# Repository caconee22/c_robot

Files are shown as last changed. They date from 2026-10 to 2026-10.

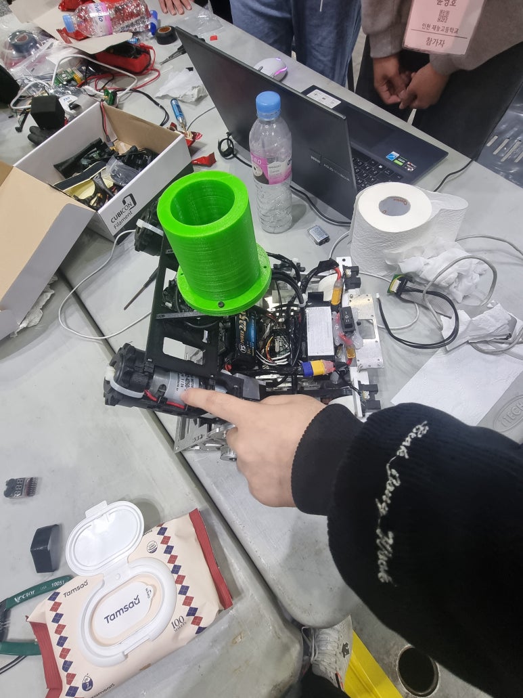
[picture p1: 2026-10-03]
img/20221027_142355.jpg

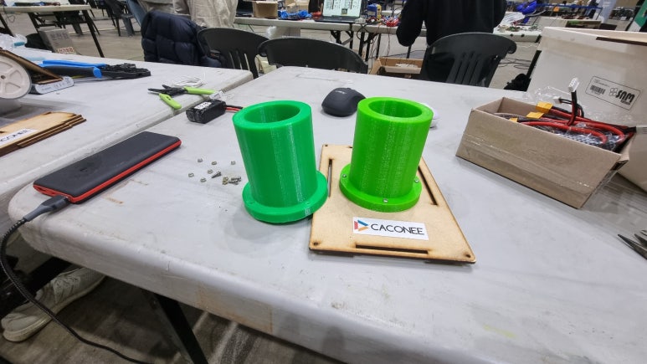
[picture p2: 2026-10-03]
img/KakaoTalk_20220726_033758780_24.jpg

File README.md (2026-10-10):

# C_ROBOT — IRC 씨름 로봇

ESP32-S3 주행 제어, 라즈베리파이 영상 처리, 회로 설계를 관리하는 저장소다.
현재 주행 펌웨어는 **V1 하드웨어**를 대상으로 한다.

처음 사용하는 사람은 [펌웨어 구조·사용법 전체 설명](ESP_MAIN/README.md)을 먼저 읽는다.
파일별 책임, 실제 FSM/안전 흐름, 센서 설정·교정, UART 규격, 모터 API, 주기와 실물 시험 순서를 설명한다.
별도 벤치의 콘솔/CSV는 [BENCH_TESTS.md](ESP_MAIN/BENCH_TESTS.md), 검토 근거는
[VERIFICATION.md](ESP_MAIN/VERIFICATION.md)에 있다. 아래는 저장소 전체와 영상 프로그램 안내다.

## 현재 진행 상황

2026-10-05 기준, ESP32 펌웨어는 부팅부터 센서·통신·안전·FSM·모터 출력까지 연결했다.
하드웨어 없는 자동 시험과 ESP32용 빌드를 통과했으며, 실제 기체 시험과 튜닝은 남아 있다.
컴파일/PC 시험 통과를 실제 차량의 완전한 동작 보증으로 해석하면 안 된다.

| 항목 | 진행 상태 |
|---|---|
| PlatformIO / Arduino / ESP32-S3 프로젝트 | 구성 완료 |
| V1 핀 정의 및 초기 안전 출력 | 구현 완료, V2 핀 배치는 미적용 |
| 부팅·리셋 원인·시작 대기 | 구현 완료 |
| SW1 인터럽트 비상정지 | 영구 래치, 브레이크 요청, 재부팅 전까지 구동 금지 |
| SW2 인터럽트 시작 버튼 | 정상 눌림·해제 각각 40ms 확인 후 한 번 시작 |
| BTS7960 좌우 모터 공용 API | 출력 제한, 정지/브레이크, 방향 설정, 상태 조회 구현 |
| 모터 명령 만료 감시 | 공용 API 기본 100ms, FSM 80ms, 별도 5ms 감시 |
| AS7341 / TCS34725 네 모서리 센서 | 빌드 시 한 종류 선택, TCA9548A 경유 읽기 구현 |
| 바닥색 판별 | 빨강·노랑·파랑·검정, 새 측정의 동일 색 3회 확인 |
| 컬러 캘리브레이션 | UART 안내식 48단계, 자세별 3초 측정, NVS 저장 구현 |
| 라즈 UART1 | 115200bps, 14바이트, CRC 없음, sequence/신선도 검사 구현 |
| 이벤트 로그 / WS2812 LED | 변경 감지·중복 억제·우선순위 표시 구현 |
| 공격 FSM | 탐색·목표 확인·정렬·접근·돌진·급정거·삽입·밀기·회피 연결 |
| PC 자동 검증 | 두 센서 구성 각각 12개 시험 그룹 통과 |
| ESP32 빌드 | 생산/센서 전용/벤치 × 두 센서 구성, 여섯 환경 통과 |
| 별도 실물 시험 펌웨어 | 모터/UART 수동/데이터/회전 정렬/추적/바닥 회피 구현, 두 센서 구성 빌드·PC 검사 통과 |
| 실물 성능·브레이크·색 임계값·전략 튜닝 | 미완료, 하드웨어 확보 후 진행 |

V1에는 IR, 거리센서, IMU, 전류센서, 엔코더, 배터리 ADC를 사용하지 않는다.
V2 회로 확장 논의와 V1 펌웨어를 혼동하지 않는다.

### 바닥 센서 최적화와 고정 기체 조건

AS7341을 약 5ms 단일 수광(F2/F3/F5/F6/F7/Clear) 연속 측정으로 변경했다.
새 측정 3회 확인은 유지한다. 수광·게인·센서별 LED·검정 임계값·비율/밝기 판별 허용 범위를
`ESP_MAIN/include/sensors/sensor_config.hpp`에 모았다. 실물 성능은 아직 검증되지 않았다.
기체는 추가 가림막 없이 자체 LED를 사용하며 10mm 단차에서 센서-바닥 간격이 3/10/20mm로 변한다.
근접 포화, 먼 거리에서 검정 오인, 색 경계 혼합을 반드시 고려한다.
교정 높이 안내와 튜닝 방법은 [센서 조정 안내](ESP_MAIN/README.md#바닥센서-조정--2026-10-05)를 읽는다.

## 저장소 안내

- [`ESP_MAIN/`](ESP_MAIN/): 주행 펌웨어와 하드웨어 없는 자동 시험.
- [`ESP_MAIN/README.md`](ESP_MAIN/README.md): 펌웨어의 의도·파일별 역할·안전/FSM·센서·통신·사용법 전체 설명.
- [`ESP_MAIN/BENCH_TESTS.md`](ESP_MAIN/BENCH_TESTS.md): 별도 시험 펌웨어의 모터/수동 UART/데이터/회전 정렬/추적/구역 회피 모드.
- [`ESP_MAIN/VERIFICATION.md`](ESP_MAIN/VERIFICATION.md): 요구사항 대응, 실행 흐름, 수정 내역, 시험 범위와 한계.
- [`ESP_MAIN/AGENTS.md`](ESP_MAIN/AGENTS.md): 사용자 요구사항과 다른 AI/개발자를 위한 작업 기준.
- [`scripts/`](scripts/): 영상 처리·시험 영상 준비 등의 파이썬 코드.
- [`COLOR_DETECTOR.md`](COLOR_DETECTOR.md): 기존 영상 검출기 실행·튜닝 안내.
- [`PCB/`](PCB/): 회로 설계 자료. 펌웨어 핀의 기준은 `ESP_MAIN/include/pins.hpp`다.
- [`PCBV2/`](PCBV2/): V2 회로/PCB, 프로젝트 라이브러리, 3D 모델, 제작 자료와 설계 백업.
  V2 자료를 보관하지만 ESP32 펌웨어는 여전히 V1 핀 배치다.

영상 처리 파이썬 코드의 존재와 현재 ESP32 패킷 규격의 종단간 호환성 검증은 별개다.
실제 라즈 송신기와 UART 연결 시험은 남아 있다.

## 펌웨어 구조

```text
ESP_MAIN/
  include/
    pins.hpp             V1 GPIO
    config.hpp           UART/공통 주기
    motor/motor_config.hpp
    sensors/sensor_config.hpp
    control/control_config.hpp
  src/
    main.cpp             전체 실행 연결
    app/                 부팅
    hardware/            초기 핀 상태/리셋 원인
    interrupts/          안전/시작 버튼
    sensors/             측정/색 판별/캘리브레이션
    communication/       라즈 UART 패킷
    system/              안전관리/로그/LED
    control/             FSM/좌우 구동 변환
    motor/               공용 제어/BTS7960 출력
    sensor_serial_test.cpp
  tests/                 생산 소스를 사용하는 PC 자동 검증
```

기본 실행은 메인 루프이며, 모터 명령 만료만 작은 FreeRTOS 태스크로 별도 감시한다.
일반 제어 루프에서 수광 시간 전체를 기다리지 않고 센서 읽기를 짧은 단계로 진행한다.
LED와 이벤트 로그는 제어 뒤에 처리한다.

```text
부팅 → 시작 대기 → SW2 눌림·해제 → 탐색
  → 목표 프레임 2회 확인 → 정렬/접근
  → 돌진 220ms → 브레이크 90ms → 스포크 삽입 350ms → 밀기
  → 목표 상실 시 제한된 시간만 밀기 → 후진 260ms → 탐색

위험색 확인 → 공격보다 먼저 위험구역 회피
SW1 입력   → 일반 실행 종료 → ESTOP만 3초마다 출력 → 재부팅 필요
```

기동 시간과 출력은 실측 전의 초기값이다. 실제 접촉이나 스포크 삽입 성공을 측정하는 제어는 아니다.

## 빌드와 업로드

PlatformIO가 설치된 터미널에서 실행한다.
현재 보드 설정은 `esp32-s3-devkitc-1`의 8MB 플래시이며 PSRAM은 사용하지 않는다.
실제 YD-ESP32-S3 사양과 업로드 포트는 실물에서 확인해야 한다.

```powershell
cd D:\C_ROBOT\ESP_MAIN
pio run -e yd_esp32_s3
```

| 환경 | 용도 | UART0 모니터 |
|---|---|---:|
| `yd_esp32_s3` | 설정 파일에서 선택한 센서의 생산 펌웨어 | 57600 |
| `yd_esp32_s3_tcs34725` | TCS34725를 지정한 생산 펌웨어 | 57600 |
| `sensor_serial_test` | 설정 파일에서 선택한 센서 전용 점검 | 115200 |
| `sensor_serial_test_tcs34725` | TCS34725 센서 전용 점검 | 115200 |
| `robot_bench` | 설정 파일의 센서로 저출력 단계별 실물 시험 | 57600 |
| `robot_bench_tcs34725` | TCS34725 실물 시험 | 57600 |

업로드와 생산 펌웨어 모니터:

```powershell
pio run -e yd_esp32_s3 -t upload
pio device monitor -b 57600
```

센서 전용 점검은 모터 핀을 초기화하거나 변경하지 않고 약 100ms마다 버튼/컬러 원시값을 출력한다.
**이 환경을 사용할 때는 모터 전원을 분리한다.** 생산 펌웨어의 안전 제어가 실행되는 환경이 아니다.

## 설정 변경 위치

| 수정할 내용 | 파일 |
|---|---|
| V1 GPIO 배치 | `ESP_MAIN/include/pins.hpp` |
| UART/로그/버튼 주기 | `ESP_MAIN/include/config.hpp` |
| PWM, 출력 상한, 모터 방향, 브레이크 조합 | `ESP_MAIN/include/motor/motor_config.hpp` |
| 센서 종류, TCA 채널, 수광 시간, 게인, 임시 색 임계값 | `ESP_MAIN/include/sensors/sensor_config.hpp` |
| 탐색·공격·회피 출력/시간, 목표 박스 기준 | `ESP_MAIN/include/control/control_config.hpp` |

기본 환경의 센서 종류는 `sensor_config.hpp`의 다음 한 줄로 선택한다.

```cpp
#define COLOR_SENSOR_MODEL COLOR_SENSOR_AS7341
// TCS34725 차량: 위 값을 COLOR_SENSOR_TCS34725로 변경
```

TCS34725 전용 환경은 빌드 옵션으로 종류를 지정한다.
종류·수광·게인·채널 설정을 바꾸면 이전 교정 데이터가 호환되지 않아 임시 임계값으로 동작한다.
센서 위치는 전방 기준 1=왼쪽 위, 2=오른쪽 위, 3=왼쪽 아래, 4=오른쪽 아래다.

## 교정과 오류 처리

시작 대기 중 UART0에 `CAL START`를 입력한다.
센서 네 개 × 바닥색 네 개 × 평행/들림/눌림 세 자세를 각각 안내받아 측정한다.
`READY` 후 3초 카운트다운과 3초 측정, `ACCEPT`로 다음 단계, 완료 후 `CAL SAVE`로 저장한다.
`RETRY`, `BACK`, `ABORT`, `STATUS`, `CAL ERASE`, `CAL MARGIN <색비율%> <밝기%>`도 지원한다.
교정 중에는 모터가 정지하며, SW2로 중단하면 새로운 눌림·해제 없이 출발하지 않는다.

- 라즈가 없거나 끊겨도 시스템 고장으로 만들지 않고 탐색 등 비전 없는 동작으로 전환한다.
- 센서 부팅 실패는 부팅을 막지 않는다. 실패 채널은 Unknown으로 남긴다.
- 센서 I2C/수광 타임아웃은 채널을 제외하고 오류를 기록한다. 자동 재초기화하지 않는다.
- 모터/애플리케이션 고장은 즉시 정지한다. 오류가 해제되었다고 자동 출발하지 않는다.
- SW1은 영구 구동 금지다. 스위치 해제나 일반 래치 해제 API로 복구할 수 없다.

## 검증 결과와 재실행

2026-10-05 코드 검토 후 결과:

| 검증 | 결과 |
|---|---|
| AS7341 PC 생산 시험 | 12그룹, assert 4,994회 통과 |
| TCS34725 PC 생산 시험 | 12그룹, assert 4,555회 통과 |
| PC 벤치 시험 | 두 센서 구성 각각 67회 통과 |
| ESP32 여섯 환경 빌드 | 모두 성공 |
| Python 핵심 시험 | 가상 이미지 기반 5개 테스트 통과 |
| 두 Pi 추적기 | 로컬 영상 각각 20프레임, 화면 없이 실행·종료 확인 |

assert 횟수에는 반복 측정 확인이 포함되며 서로 다른 시나리오 개수는 아니다.
실제 생산 소스와 `setup()/loop()`를 가짜 GPIO/UART/I2C/NVS에 연결해 검증한다.
네이티브 g++가 필요하며 PATH 또는 PlatformIO의 `toolchain-gccmingw32`를 사용한다.

```powershell
cd D:\C_ROBOT\ESP_MAIN
.\tests\run_host_tests.ps1
.\tests\run_host_tests.ps1 -Demo
.\tests\run_host_tests.ps1 -Bench
```

`-Demo`는 공격 상태와 좌우 출력을 가상 입력으로 보여주는 텍스트 데모다.
시험 상세와 수정한 오류는 [검증 기록](ESP_MAIN/VERIFICATION.md)에 정리했다.

## 영상 코드의 구성과 의도

바닥의 네 색 판별은 ESP32의 광학 센서 코드다. 아래 Python 코드의 녹색 타워 검출과
교정 데이터를 공유하지 않는다. 라즈는 영상만 처리하고, 주행 판단/안전은 ESP32에서 수행하는 구조다.

```text
카메라 또는 영상 파일
  → 저해상도 BGR/ExG 후보 → 후보 ROI 확대 → 원본 해상도 BGR/ExG/HSV/Lab 검증
  → 마스크 정리 → 연결 성분 / 후보 선택(최대2개) → 전역 좌표
  → 텍스트 / JSON / 화면 / 성능 보고서
  → [미구현: 14바이트 UART 패킷 송신] → ESP32 RaspberryLink → FSM → 모터
```

현재 Pi 추적기는 pyserial/UART 송신을 하지 않는다. `--json`은 좌표를 표준출력에 쓰는 옵션이다.
그 JSON에는 현재 박스 폭/높이 등 ESP 패킷 필드가 전부 들어 있지도 않다.
실물 ALIGN/FOLLOW/AVOID에는 규격 송신기가 필요하며, JSON을 그대로 UART1에 보내면 안 된다.
50fps 카메라 설정도 실제 처리/송신 50Hz를 증명하지 않는다.

| 파일 | 역할과 사용 의도 |
|---|---|
| `scripts/color_detection_core.py` | 원본 전체 프레임 검출 기준. BGR/ExG/HSV/Lab, 융합, 모폴로지, 연결 성분, 후보 자료형 |
| `scripts/color_detection_lightweight.py` | 작은 후보 영상에서 ROI를 찾고 원본 ROI만 정밀 검증. 전역 bbox/centroid/contour 변환으로 계산량 감소 |
| `scripts/pi_green_tracker.py` | 공유 검출기를 파일/USB카메라/Picamera2에 연결. JSON/미리보기/파일 반복/측정/내보내기 UI |
| `raspberry_pi_green_tracker_single.py` | 복사하기 쉬운 단일 파일 Pi 검출기. 상단 고정 녹색 임계값과 미소 타워의 엄격한 필터 |
| `scripts/color_detector_ui.py` | 실행 입구. 기본 단계별 wizard, --advanced-ui 전체 설정 UI, --benchmark 화면 없는 측정 |
| `scripts/color_detector_wizard.py` | 순서대로 BGR→ExG→HSV→Lab→융합→후처리 튜닝, ROI 자동 조정, 설정/스냅샷/내보내기 |
| `scripts/benchmark_lightweight_compare.py` | 동일 영상의 전체 프레임/ROI 검출 시간·마스크·후보 비교. 실행 순서를 번갈아 편향 완화 |
| `scripts/color_detector_export.py` | 기준 검출기의 원본/결과/각 마스크를 분석 영상으로 저장 |
| `scripts/export_lightweight_full_video.py` | ROI 검출기의 전체 분석 영상 저장. 실제 제어 루프에서 인코딩하지 않고 별도 실행 |
| `scripts/prepare_test_video.py` | 시험 영상을1920×1080/50fps로 리사이즈·시간 기반 프레임 반복, 메타데이터 검증 |
| `scripts/green_cylinder_video_live.py` | 초기 녹색 검출기 재생/슬라이더/마스크/샘플 저장. 현재 공유 검출기와 별도 실험 구현 |
| `scripts/green_cylinder_image_batch.py` | img 이미지의 초기 녹색 후보를 일괄 검출해 주석 이미지/CSV 생성 |
| `scripts/preprocess_green_images.py` | 초기 영상 검출기 기본 설정으로 이미지·마스크·검출 데이터를 준비 |
| `scripts/opencv_green_cylinder_demo.py` | 합성 도형으로 OpenCV 검출/마스크 저장의 간단한 설치 점검 |
| `scripts/face_tracking_demo.py` | Haar 얼굴 검출 설치 점검. 경기 타워 검출이나 FSM에 사용하지 않음 |
| `cv_live_view.py` | 별도 합성 영상 data/synthetic.avi의 루프 표시 예제. 그 입력 파일이 있어야 하며 주요 Pi 실행 입구가 아님 |
| `scripts/generate_htd5m_20t_pulley.py` | CadQuery/DXF 기반 기구 STEP/STL 생성. 주행/CV와 무관, 별도 CadQuery 환경 필요 |
| `tests/test_vision.py` | 가상 대상/비대상색·좌표·ROI 병합·경계·마스크 형식 검증. 실제 카메라 성능 시험은 아님 |
| `setup_raspberry_pi.sh` | Raspberry Pi OS의 OpenCV/NumPy/Picamera2 시스템 패키지 설치 |
| `run_pi_tracker.sh` | 저장소 위치로 이동 후 Pi 카메라 입력50fps로 공유 추적기 실행 |

공유 검출기는 `config/color_detector_last.json`을 기본값 위에 덮어쓴다.
단일 파일 추적기는 이 JSON을 읽지 않는다. 따라서 UI 설정을 저장했다고 두 추적기 임계값이
동시에 바뀌지는 않는다. 단일 파일은 상단 상수를 조정해야 한다.
예를 들어 순수(0,255,0) 녹색도 단일 파일의 좁은 HSV/Lab 범위 밖이면 거부될 수 있다.
저해상도 후보를 놓친 대상은 ROI 정밀 검증에 들어오지 않는다. 두 방식의 검출 결과가 항상 같지는 않다.

### 로컬 Windows에서 실행

프로젝트 루트에서 가상환경 Python을 사용한다. 기존 `.venv`가 없다면 생성 후 의존성을 준비한다.
핵심 CV 실행에는 OpenCV/NumPy가 필요하고 저장소 전체 `requirements.txt`는 다른 실험용 패키지도 포함한다.

```powershell
cd D:\C_ROBOT
python -m venv .venv
.\.venv\Scripts\python.exe -m pip install opencv-python==4.12.0.88 numpy
# 기존 환경을 쓰면 위 생성/설치는 생략
.\.venv\Scripts\python.exe scripts/pi_green_tracker.py --source dataset/videos/irc_highlight_1080p50.mp4 --preview --realtime
```

Q 종료, M 마스크 표시, E 전체 파일 내보내기. `--realtime`은 파일 원래 FPS에 맞춰 기다리므로
순수 처리 성능 시험에서는 빼야 한다. `--loop`는 파일을 반복한다.
GUI는 실제 데스크톱 세션이 필요하다. 파일/카메라 해상도와 처리 시간은 별도 확인한다.

화면 유무 비교와 좌표 출력:

```powershell
.\.venv\Scripts\python.exe scripts/pi_green_tracker.py --quiet --benchmark --max-frames 300
.\.venv\Scripts\python.exe scripts/pi_green_tracker.py --quiet --benchmark --max-frames 300 --preview
.\.venv\Scripts\python.exe scripts/pi_green_tracker.py --json --max-frames 20
.\.venv\Scripts\python.exe raspberry_pi_green_tracker_single.py --source dataset/videos/irc_highlight_1080p50.mp4 --preview
.\.venv\Scripts\python.exe scripts/color_detector_ui.py
```

벤치 보고서는 `output/color_detector/benchmarks`에 저장된다. 기본10프레임 예열은 통계에서 제외한다.
검출 시간과 입력/표시/대기 포함 loop 시간을 구분한다. 일반 실행의 FPS 이력은60프레임으로 제한하고,
명시적 --benchmark는 전체 통계를 위한 목록을 보관하므로 장시간 운전 옵션이 아니라 유한 시험용으로 쓴다.
전체 프레임/ROI 비교가 필요하면 benchmark_lightweight_compare.py를 실행한다.
각 보조 도구의 옵션은 `--help`, 튜닝·GUI·내보내기의 상세 키는 [COLOR_DETECTOR.md](COLOR_DETECTOR.md).

### 라즈베리파이에서 실행

Raspberry Pi OS의 Picamera2는 시스템 패키지와 카메라 드라이버가 필요하다.
일반 PC에 pip로 설치한 OpenCV만으로 카메라 입력이 되지는 않는다.

```bash
bash setup_raspberry_pi.sh
python3 -m venv --system-site-packages .venv
.venv/bin/python scripts/pi_green_tracker.py --source camera --fps 50 --preview
# 또는 시스템 Python 실행 래퍼:
bash run_pi_tracker.sh --preview
```

이미 설정한 환경이라면 설치를 반복할 필요 없다. 현재 Windows 검토는 라즈에 원격 접속하거나
패키지를 변경하지 않았다. 실행 중인 카메라/GUI/50Hz UART의 실측과 종단간 검증은 남아 있다.

### Python 검증 재실행

```powershell
.\.venv\Scripts\python.exe -m unittest discover -s tests -v
.\.venv\Scripts\python.exe -m compileall -q scripts tests cv_live_view.py raspberry_pi_green_tracker_single.py
```

이 검증은 주요 공유/단일 검출기의 오프라인 논리를 검사한다. 모든 GUI/내보내기/CAD 경로,
실제 영상의 정답 정확도, 카메라 성능과 UART 송신까지 보증하는 시험은 아니다.
영상·출력·가상환경·빌드 결과물은 Git에 올리지 않으므로 새 clone에는 기본 시험 영상이 없을 수 있다.
영상이 없으면 별도로 준비하거나 --source로 실제 파일을 지정한다.

## 기체 설계와 기동 전략 — 2026-10-10

이 절은 제작 전 기구 설계와 경기 전략의 기준을 기록한다. 사진으로 분석한 다른 팀 로봇의 치수는
공개 도면이 아닌 원근 보정 기반 추정값이며, 아래 기동 시간·거리·출력은 실물 시험 전에는 확정값으로
사용하지 않는다. 현재 생산 펌웨어가 아래 모든 기동을 구현했다는 뜻도 아니다.

### 비교 기체에서 얻은 기준

| 구분 | 추정 휠베이스 | 관찰한 설계 의도 |
|---|---:|---|
| 비교 로봇 1 | 약 110mm | 짧은 휠베이스와 전방 모터 배치로 일반 탱크턴과 전방 하중을 확보 |
| 비교 로봇 2 | 약 170mm | 모터를 전방으로 기울여 무게중심을 앞에 두고, 큰 회전에는 뒤를 들어 앞바퀴만으로 회전 |
| 비교 로봇 3 | 약 140mm | 넓은 바퀴와 네 모터 직결로 회전 효율보다 구동력을 우선 |
| 이전 자작 기체 | 180mm | 31mm 폭의 연한 바퀴와 긴 휠베이스가 결합되어 제자리회전 시 심한 횡끌림·변형·털림 발생 |

사진 추정값은 설계 비교에만 사용한다. 이전 기체의 180mm와 실제 털림은 확인된 경험값이므로 새 기체의
휠베이스 결정에서 사진 추정보다 우선한다.

### 확정한 기본 기구 방향

- 휠베이스는 가변형 대신 **129mm 고정**으로 확정한다.
- 좌우 바퀴 중심거리는 외폭 약 300mm와 바퀴 폭 35mm를 가정해 약 265mm를 목표로 한다.
- 바퀴는 우선 외경 약 60mm, 폭 35mm, 식품 몰드용 Shore A40 실리콘을 기준으로 한다.
- 이전 180mm에서 129mm로 줄이면 기하학적 횡슬립 거리는 약 28.3% 감소한다.
- 한 바퀴가 제자리 360도 회전할 때의 횡방향 이동량 근사는 `pi * 휠베이스`이므로,
  180mm에서는 약 565mm, 129mm에서는 약 405mm다.
- 단순 비교에서 `휠베이스 / 좌우 중심거리`는 약 `129 / 265 = 0.487`이다.
- 120mm는 회전성은 더 좋지만 전방 오버행과 피칭 부담이 커지고, 140mm는 앞축 편중과 횡끌림이
  증가하므로 두 값 사이에서 검토한 뒤 129mm를 최종 고정값으로 선택했다.
- 모터는 움직이는 장력 조절 구조로 만들지 않는다. 벨트 장력은 별도 아이들러 구조로 조정한다.
- 하판과 모터 고정부·사이드 프레임, 전방 스키드는 6061 알루미늄을 사용한다. 힘이 작은 고정 파트는
  무게와 가공비를 줄이기 위해 3D 출력물을 우선한다.
- 사이드판과 힘을 받는 모터 고정부는 현장 보유 자재에 맞춰 **6061 5T를 유지**한다. 하판은 전면을
  채운 판이 아니라 트러스 형상으로 경량화한다. 4T는 별도 구매와 재고 문제 때문에 이번 제작에서 쓰지 않는다.
- 모터 고정부는 고정형이며 슬롯으로 움직이지 않는다. 레이저 절단판에는 슬롯 접시가공을 기대하지 않고,
  모터와 풀리 사이의 볼트 머리 간섭은 접시머리 볼트와 별도 형상 검토로 해결한다.
- 휠 축은 F608ZZ 계열 플랜지 베어링과 내경 8mm 축을 기준으로 한다.

### 확정한 벨트 구동계

두 구동 구간 모두 HTD5M 20T 풀리, 피치 5mm, 벨트 폭 15mm를 사용한다. 20T 풀리의 피치원은
`100 / pi = 31.83099mm`이며, 풀리 외경이나 톱니 뿌리원을 벨트 길이 계산에 대신 사용하지 않는다.

| 구간 | 중심거리 | 구매 벨트 | 아이들러가 없을 때 피치 길이 | 용도 |
|---|---:|---:|---:|---|
| 전륜-후륜 | 129mm | 360mm | 358mm | 좌우 각 측의 두 바퀴 연결 |
| 모터-전륜 | 79mm | 260mm | 258mm | 높은 위치의 모터에서 전륜으로 전달 |

벨트 길이는 같은 20T 풀리 두 개일 때 `L = 2C + 100mm`로 계산한다. 구매한 260/360mm 벨트는 각각
아이들러로 약 2mm의 추가 피치 경로와 초기 장력을 만든다. 모터는 장력 조절을 위해 슬라이드하지 않는다.

모터-전륜 260mm 구간의 현재 기준은 다음과 같다.

- 아이들러는 608 계열 `8 x 22 x 7mm` 베어링과 M8 볼트를 사용한다.
- 위쪽 풀리 중심 기준 이론적인 무장력 위치는 왼쪽 18.249mm, 아래 36mm다.
- 현재 검토 STEP은 왼쪽 17.9255mm, 아래 35mm이며 올바른 피치원으로 계산한 경로는 약
  260.169mm다. 약 0.065%의 초기 간섭량이므로 장력 위치 후보로 사용할 수 있다.
- 추천 M8 슬롯은 폭 9mm, 전체 길이 16mm, 중심 이동량 7mm다. 중심 위치를 왼쪽 17~24mm
  범위로 두면 17mm 쪽은 장력을 늘리고 24mm 쪽은 조립 여유를 만든다.
- 슬롯에는 외경 18mm 이상 평와셔를 사용하고, 슬롯 외곽에서 판재 끝까지 최소 5mm, 가능하면 8mm
  이상의 살을 남긴다.
- M8 볼트는 베어링 내륜과 맞는 비나사부가 베어링 폭을 지나도록 길이와 반나사 구간을 확인한다.
- 구하기 어려운 스페이서는 3D 출력하되, 베어링 내륜을 누르는 면이 외륜이나 실드와 간섭하지 않게 한다.

[`mechanical/belt/`](mechanical/belt/)에는 피치선 검사용 DXF, 1mm 단순 벨트 외형, 슬롯 DXF,
치수 그림과 현재 STEP 검토본을 보관한다. STEP 검토본은 제작 승인본이 아니다. 현재 파일에는
`Ø31.183mm` 원이 들어 있어 `Ø31.831mm` 피치원과 숫자 순서가 다르고, 아이들러 주변 벨트 경계도
R10~R11로 베어링 안쪽에 놓여 있다. 최종 물리 외형은 베어링 표면 R11 바깥쪽인 R11~R12에 두고,
벨트 길이는 별도의 피치선으로 검증해야 한다.

회전 저항을 단순 쿨롱 마찰로 보면 저항 모멘트는 대략 다음과 같다.

```text
M_scrub ~= mu_y * W * L / 2
```

다만 실제 기체는 앞축 하중이 크므로 회전 중심이 앞축 쪽으로 이동하고 가벼운 뒤축이 더 많이 미끄러질
수 있다. 따라서 위 식은 균등 하중 기체의 비교식이며 실제 저항을 그대로 보장하지 않는다. 넓고 부드러운
실리콘 타이어에서는 단순 마찰 외에 횡변형, 히스테리시스, 점착-미끄러짐 반복이 털림을 만든다.

### 무게중심과 축 하중

현재 무게 추정에서 전방에 배치되는 주요 부품은 모터 두 개 약 1,090g, 모터 브래킷 두 개 약 400g,
배터리 약 180g, 전방 슬라이드 약 200g으로 합계 약 1,870g이다. 이는 4,500g 기체의 약 41.6%다.
실제 위치가 확정되지 않았으므로 정확한 무게중심은 Fusion의 부품별 무게중심 좌표로 다시 계산해야 한다.

앞축을 `x=0`, 뒤쪽을 양수로 두면 다음 식을 사용한다.

```text
x_CG = sum(m_i * x_i) / sum(m_i)
앞축 하중 비율 = 1 - x_CG / 휠베이스
뒤축 하중 비율 = x_CG / 휠베이스
```

129mm 휠베이스에서 무게중심이 앞축 뒤 약 42mm라면 앞축 약 67.4%, 뒤축 약 32.6%가 된다.
설계 목표는 앞축 약 65~70%, 뒤축 약 30~35%다. 4.5kg 기준 앞축 약 2.93~3.15kg,
뒤축 약 1.35~1.58kg 범위다. 앞축이 70%를 크게 넘으면 전방 스키드는 잘 눌리지만 후륜 접지와 착지
안정성이 부족할 수 있다. 배터리는 최종 계측 후 앞뒤 위치를 조절할 수 있게 고정한다.

무게중심 높이는 약 60mm를 초기 목표로 한다. 모터 두 개와 배터리는 전륜 위쪽에 집중하고, 약 110g의
컬러타워도 전륜 위 높은 위치에 놓아 리어리프트 제동 기동에 활용한다. 반면 PCB, 라즈베리파이와
모터드라이버는 중앙·하부에 배치해 과도한 전복성을 억제한다. 모터 축과 전륜 축의 79mm 간격은 벨트
규격뿐 아니라 전체 무게중심 높이에 직접 영향을 주므로 완성 CAD의 질량 특성으로 다시 확인한다.

경기 중량 제한은 4,500g이며 측정 허용범위를 포함한 절대 상한은 4,545g으로 관리한다. 허용범위는
설계 여유가 아니므로 CAD 목표는 4,500g보다 충분히 낮게 둔다. 5T 6061 사이드판은 유지하고 트러스와
불필요한 면적을 줄인다. 출력물은 낮은 하중의 마운트와 스페이서에 사용하며, 전방 슬라이드 약 200g,
모터 두 개 약 1,090g, 배터리 약 180g, 컬러타워 약 110g처럼 실제 계측값이 있는 항목을 우선한다.
608 베어링, 샤프트 칼라 8개, 배터리 벨크로, M8 너트·와셔, 스위치와 비상정지 스위치, 커넥터와
수축튜브는 누락되기 쉬운 항목으로 별도 계상한다.

축 하중은 완성 기체에서 앞바퀴 두 개를 저울에 올리고 뒷바퀴는 같은 높이의 받침에 둔 상태로 측정한다.
반대 축도 같은 방식으로 확인하고 두 측정값의 합이 전체 중량과 맞는지 검사한다.

### 전방 스포크와 스키드

전방은 낮은 침투부와 급경사 상승부를 결합한 2단 형상을 우선한다.

- 첫 구간: 바닥 기준 약 30도, 수평 길이 약 30~40mm
- 전환 높이: 약 17~23mm
- 뒤 구간: 약 65~70도
- 전환부: 상대 전방판이 걸리지 않도록 약 R5~10mm로 연결
- 전환부 아래에는 충격과 굽힘을 받는 보강을 둔다.

30도 구간은 급제동 시 바닥을 스치며 상대 아래로 들어가는 역할을 하고, 이미 상대 전방 하중을 줄인 뒤
65~70도 구간이 빠르게 들어 올리는 역할을 한다. 70도 단독 경사는 초기 침투에서 벽처럼 작용할 수 있다.
스포크 끝은 경기장 표면을 손상시킬 정도로 날카롭게 만들지 않으며 실제 규정과 표면에서 확인한다.

### 바닥 센서의 기구 배치

바닥 센서는 총 네 개를 유지한다. 전방 좌우 두 개는 독립적으로 경계를 먼저 확인하고, 후방 두 개는
기체 구조상 중앙에 가깝게 놓이므로 제어에서 하나의 후방 위험 그룹처럼 OR 처리할 수 있다. 후방 센서는
밀리고 있는 사실을 새로 알려도 기동이 달라지지 않는 상황이 많지만, 잘못된 후진 회피가 길어지는 경우와
상대 공격으로 후방부터 경계에 들어가는 경우의 안전 입력으로 남긴다.

충돌 시 부러질 수 있는 돌출 센서 마운트나 바퀴 뒤쪽으로 내려오는 구조는 사용하지 않는다. 기체가 들렸을
때 바퀴 다음으로 센서가 바닥에 닿지 않게 하판 안쪽에 보호하고, 3/10/20mm 센서-바닥 간격과 10mm
단차, 하부 그늘과 센서 내장 백색 LED 조건을 모두 교정에 포함한다. 센서 위치 변경은 펌웨어의 네 채널
순서와 함께 갱신한다.

### 경기 기동의 공통 우선순위

```text
1. 비상정지와 모터 명령 만료 안전
2. 위험색·경계 회피
3. 접촉 중 밀기 유지 또는 안전 이탈
4. 리어리프트 공격
5. 리어리프트 턴
6. 일반 정렬·추적·탱크턴
7. 스타트 정렬과 탐색
```

경계 센서가 위험을 확인하면 모든 공격·리어리프트 기동보다 먼저 회피한다. 현재 V1은 IMU, 엔코더,
거리센서, 전류센서를 사용하지 않으므로 자세를 직접 확인했다고 가정하지 않는다. V1에서 리어리프트를
시험한다면 카메라 목표 정보와 제한된 시간 기반 단계로 시작하고, 출력 상한을 낮춘 실물 시험으로 시간을
결정한다. 센서를 추가하는 V2 전략과 V1 구현을 혼동하지 않는다.

### 스타트 정렬 기동

우리 시작점, 경기장 중앙, 상대 시작점이 일직선이라는 경기장 배치를 이용한다.

```text
우리 시작점 -> 경기장 중앙 -> 상대 시작점
```

1. 설치 시 정해진 기준 방향을 사용한다.
2. 시작 후 중앙과 상대 시작점이 놓인 선으로 우선 정렬한다.
3. 카메라에서 상대를 확인하면 일반 추적으로 전환한다.
4. 상대가 즉시 보이지 않으면 중앙 방향의 제한된 이동과 탐색을 수행한다.

목적은 시작 직후 불필요한 전방위 탐색을 줄이고 상대가 있을 가능성이 가장 높은 선을 먼저 점유하는 것이다.
실제 시작 배치 오차와 상대의 즉시 회피를 고려해 장시간 직진을 고정 명령으로 사용하지 않는다.

### 일반 추적과 공격

기존 FSM의 기본 공격 흐름은 다음과 같다.

```text
탐색 -> 목표 확인 -> 정렬 -> 접근 -> 돌진 -> 급정거 -> 스포크 삽입 -> 밀기
```

현재 코드의 돌진 220ms, 브레이크 90ms, 삽입 350ms는 실물 검증 전 초기값이다. 카메라의 상자 중심으로
방향 오차를 판단하고, 거리센서가 없는 V1에서는 상자 크기를 실제 거리의 대용값으로 교정해야 한다.

### 리어리프트 공격

상대가 설정 거리 안에 있고 방향이 충분히 일치할 때, 전진 가속 뒤 강한 제동으로 뒤축 하중을 줄이고
전방 스포크가 바닥을 스치며 상대 아래로 들어가게 하는 공격이다.

```text
정렬 -> 전진 가속 -> 짧은 강제 제동 -> 스포크 하강·침투 -> 양쪽 전진 출력 -> 밀기
```

- 방향 오차가 작은 경우에만 사용한다. 초기 기준은 약 ±10~15도 이내로 두되 실측으로 조정한다.
- 제동 시점은 고정 거리 하나가 아니라 접근 속도와 영상·제어 지연을 함께 고려한다.
- 너무 일찍 제동하면 접촉 전에 뒤축이 내려오고, 너무 늦으면 스포크가 내려가기 전에 충돌한다.
- 제동 직후에는 양쪽을 전진시켜 30도 저각 구간을 상대 아래로 밀어 넣는다.
- 드라이버의 능동제동 전류와 배터리의 회생 전압 수용 여부를 실물에서 확인한다.

앞축을 기준으로 뒤축이 들리기 시작하는 단순 조건은 다음과 같다.

```text
a > g * x_CG / h_CG
```

`x_CG`는 앞축에서 무게중심까지의 뒤쪽 거리, `h_CG`는 무게중심 높이다. 예를 들어 `x_CG=42mm`,
`h_CG=60mm`라면 약 0.70g보다 큰 감속이 필요하다. 타이어 변형, 스키드 접촉, 모터 제동 특성 때문에
계산값만으로 동작을 보장하지 않는다.

### 리어리프트 턴

상대와의 방향 오차가 커서 일반 탱크턴의 횡끌림이 커질 때 사용하는 특수 회전이다.

```text
짧은 전진 가속 -> 강제 제동 -> 뒤축 하중 감소 또는 이륙
-> 앞바퀴 좌우 반대 출력 -> 목표 방향 직전에 감속 -> 뒤축 착지 -> 추적 복귀
```

뒤축이 실제로 들리면 접지 휠베이스가 거의 0이 되어 129mm 휠베이스의 횡끌림을 우회할 수 있다.
초기 사용 조건은 큰 방향 오차 약 70~100도 이상을 후보로 두되, 고정값으로 확정하지 않는다.
전방에 가속 공간이 없거나 경계가 가까우면 사용하지 않는다.

착지 시 공중에서 회전하던 뒤 바퀴가 바닥과 큰 속도 차이로 닿으면 벨트, 풀리, 샤프트, 베어링에 충격이
생긴다. 목표 각도 전에 회전 출력을 줄이고 착지 직전 좌우 속도 차이를 완화해야 한다. 앞바퀴 두 개와
전방 구조는 순간적으로 기체 전체 하중을 받을 수 있게 설계한다.

### 하나의 리어리프트 공통 단계

공격과 회전을 별개의 제동 튜닝으로 만들지 않고 공통 준비 단계를 공유한다.

```text
REAR_LIFT_PREPARE
  -> 제한된 전진 가속
  -> 제한 시간 강제 제동
  -> 목적에 따라 분기
       공격: 양쪽 전진
       회전: 좌우 반대 출력
```

V1에는 자세 센서가 없으므로 `뒤축 들림 감지 완료` 같은 조건을 현재 하드웨어의 실제 입력처럼 구현하면
안 된다. 실물 시험 전에는 이 전략을 생산 기본값으로 활성화하지 않고, 저출력 벤치 모드와 안전 지그에서
제동 시간, 이동 거리, 드라이버 온도, 벨트 충격을 먼저 확인한다.

### 외부 서버 영상처리와 로컬 폴백 전략

영상처리 부하는 가까운 전용 공유기의 로컬 네트워크에 연결된 외부 서버 PC로 옮기는 구성을 시험한다.
외부 서버는 영상 인식만 담당하고, 전략 FSM·모터 출력·바닥 경계 회피·비상정지는 계속 ESP32에서
수행한다. 외부 서버가 좌우 모터 출력을 직접 결정하지 않는다.

```text
카메라
  -> 라즈베리파이: 1280x720 저지연 영상 송출
  -> 전용 5GHz 공유기
  -> 유선 연결된 서버 PC: 상대 검출
  -> UDP로 목표 좌표·박스·신뢰도 반환
  -> 라즈베리파이: 원격/로컬 결과 선택 및 14바이트 UART 변환
  -> ESP32: 기동 선택과 모터 제어
```

초기 시험은 1280x720, 최대 50FPS, H.264 저지연 RTP/UDP 송출을 기준으로 한다. B프레임과 긴 수신
버퍼를 사용하지 않고, 처리 대기열은 최대 한 프레임만 유지한다. 처리가 밀리면 오래된 프레임을 끝까지
처리하지 않고 버린 뒤 최신 프레임으로 넘어간다. 서버는 필요하면 수신한 압축 영상을 재인코딩 없이
저장하고, 검출 결과와 FSM 로그는 별도로 기록한다.

서버가 반환하는 최소 정보는 다음과 같다.

```text
frame_id, capture_time, target_x, target_y,
target_width, target_height, confidence, target_count
```

서버의 1280x720 좌표는 현재 UART 규격인 1920x1080 좌표로 변환한다. 단순 전체 화면 매핑이면
`x *= 1.5`, `y *= 1.5`를 적용한다. 원격 검출기와 로컬 검출기가 각자 UART sequence를 만들지 않고,
라즈베리파이의 최종 결과 선택기가 출처와 관계없이 하나의 연속 sequence를 생성한다.

#### 원격 우선과 로컬 자동 전환

원격 서버 결과를 기본으로 사용하되 라즈베리파이의 로컬 검출기를 폴백으로 유지한다. 원격 정상 상태에서
로컬 검출기를 완전히 종료하면 장애 시 초기화 지연 때문에 즉시 전환할 수 있으므로, 카메라 스트림과
검출기를 준비한 상태로 유지하거나 낮은 주기로 대기시킨다.

```text
REMOTE_ACTIVE
  -> 원격 결과 지연 증가 -> REMOTE_DEGRADED
  -> 새 원격 결과가 120ms 동안 없음 -> LOCAL_ACTIVE
  -> 원격 결과가 5~10프레임 연속 정상 -> REMOTE_ACTIVE
```

전환 기준의 초기값은 다음과 같다.

| 조건 | 처리 |
|---|---|
| 원격 결과 나이 0~60ms | 원격 결과 정상 사용 |
| 60~120ms | 원격 불안정 상태로 기록, 최신 결과만 제한적으로 사용 |
| 120ms 이상 새 결과 없음 | 로컬 검출 결과로 즉시 전환 |
| 1초 이상 응답 없음 | 서버 완전 단절로 기록하되 이미 로컬로 운전 중이어야 함 |
| 원격 결과 5~10프레임 연속 정상 | 복구 후보, 지연과 좌표 일치 확인 후 원격으로 복귀 |

1초는 주행 중 폴백을 시작하는 시간이 아니다. 1m/s 주행에서는 1초 동안 1m를 이동할 수 있으므로 현재
ESP32 영상 신선도와 같은 120ms를 초기 폴백 기준으로 사용한다. 원격 패킷 하나만 도착했다고 즉시 복귀하면
원격과 로컬 사이를 반복 전환할 수 있으므로 연속 정상 프레임과 복구 히스테리시스를 사용한다.

원격과 로컬 출처가 바뀐 직후 약 200ms 동안은 좌표·거리 추정 차이를 고려해 리어리프트 공격과
리어리프트 턴을 금지하고 일반 정렬과 제한된 접근만 허용한다. 바닥 경계 회피, SW1 비상정지,
모터 명령 만료 감시는 영상 출처와 관계없이 항상 우선한다. 원격과 로컬 결과가 모두 오래되면 마지막
표적을 계속 추적하지 않고 목표 상실 상태로 전환한다.

#### 채택 판단 기준

이 구성은 아직 구현·검증되지 않았다. 전용 공유기를 가까이 두고 서버를 유선 연결한 상태에서 다음을
측정한 뒤 생산 전략 채택 여부를 결정한다.

- 서버 영상처리 평균 40FPS 이상, 목표 50FPS
- 촬영부터 로봇의 결과 수신까지 평균 약 30ms 이하
- 95% 지연 50ms 이하, 장시간 큐 누적 없음
- 패킷 누락 약 1% 이하
- 통신 단절 후 120ms 안에 로컬 결과로 전환
- 원격 복구 중 반복 전환이나 오래된 좌표 재사용 없음
- 서버가 끊겨도 바닥 회피와 모터 안전 기능은 정상 유지

리어리프트의 가속·제동·삽입·회전 단계는 네트워크 왕복으로 하나씩 명령하지 않는다. 서버는 목표 위치와
기동 시작 조건에 필요한 영상 정보만 제공하고, 일단 시작한 시간 기반 기동은 ESP32가 로컬에서 끝낸다.
대회에서 외부 컴퓨터와 무선 통신을 허용하는지는 실제 적용 전에 해당 연도 규정으로 별도 확인한다.

## 다음 단계

1. 모터 전원을 분리하고 센서 종류·TCA 채널·원시값부터 확인한다.
2. 출력 상한을 낮추고 바퀴를 띄워 모터 방향, SW1 브레이크, SW2 시작을 확인한다.
3. 실제 바닥색과 자세별로 수광·게인·임계값을 교정한다.
4. 라즈 UART 송신·분리·재부팅을 종단간 시험한다.
5. 위험색 회피를 먼저 시험한 뒤 공격 출력을 올리고 기동 시간을 튜닝한다.

센서 100Hz는 목표이지 현재 실측 달성 결과가 아니다. AS7341 전체 스펙트럼은 두 번의 수광이 필요하다.
실제 브레이크 효과, 시간 기반 기동의 기체 안정성, 바닥과 상대 로봇 표면 구분은 실물 검증이 필요하다.
영상·가상환경·빌드 산출물은 `.gitignore`에 따라 제외한다.
2026-10-05 추가 작업 반영에는 남은 PCBV2 자료와 파이썬 코드, PNG 실행 화면도 함께 포함했다.

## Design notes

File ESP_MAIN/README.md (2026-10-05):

# ESP_MAIN — V1 펌웨어 구조와 사용법

ESP32-S3 / Arduino / PlatformIO 기반 씨름 로봇 제어 코드다.
이 문서는 작업 이력이 아니라 **모듈을 나눈 의도, 실행 순서, 설정 방법과 사용법**을 설명한다.
최신 검토 기준은 2026-10-05다. 부팅·버튼·센서·교정·비전 수신·안전관리·FSM·모터가 연결돼 있다.
생산/벤치 코드의 PC 시험과 여섯 ESP32 빌드는 통과했지만 실제 수광·브레이크·제동거리·
색 임계값·공격 전략은 미검증이다. 빌드 성공을 실제 차량의 완전한 동작 보증으로 해석하지 않는다.

중요한 연결 공백: 저장소의 라즈 영상 프로그램은 현재 화면/텍스트/JSON 출력만 한다.
**ESP32용 14바이트 UART 송신기는 아직 연결되지 않았다.** ESP32 수신부 구현과
카메라부터 모터까지의 종단간 동작 완료는 다르다.

## 1. 하드웨어 범위

현재 코드는 **V1**이다. PCBV2 핀을 적용하지 않는다.
네 모서리 컬러 센서만 사용하며 IR·IMU·전류·엔코더·배터리 ADC는 없다.
한 차량에 AS7341 네 개 또는 TCS34725 네 개를 사용한다. 두 종류를 동시에 섞는 구성은 아니다.
모터 1은 왼쪽, 2는 오른쪽이며 엔코더 속도/PID가 아닌 PWM 명령으로 구동한다.

```text
             기체 전방 / 카메라
           S1(FL)       S2(FR)
           왼쪽 모터    오른쪽 모터
           S3(RL)       S4(RR)
```

S1..S4는 사용자 표시 번호다. 배열 인덱스와 TCA 기본 채널은 0..3이다.
동일 주소 센서의 충돌을 막기 위해 매 거래 전에 TCA 채널 하나만 선택한다.

| 신호 | GPIO | 의미 |
|---|---:|---|
| SW1 / SW2 | 15 / 16 | GND 연결 능동 LOW, 내부 풀업 |
| UART0 TX / RX | 43 / 44 | 이벤트·교정 또는 벤치 콘솔, COM/SiK 공유 |
| UART1 TX / RX | 17 / 18 | 라즈 UART, 상대 TX→ESP RX, 공통 GND |
| I2C SDA / SCL | 11 / 12 | TCA9548A 기본 0x70 |
| 내장 / 외부 WS2812 | 48 / 13 | 각각 1개 |
| 왼쪽 LPWM / RPWM | 42 / 41 | BTS7960 Motor 1 |
| 왼쪽 LEN / REN | 40 / 39 | V1 독립 EN 핀 |
| 오른쪽 LPWM / RPWM | 38 / 47 | BTS7960 Motor 2 |
| 오른쪽 LEN / REN | 21 / 14 | V1 독립 EN 핀 |

`include/pins.hpp`는 커넥터 순번이 아니라 Arduino에 직접 넣는 GPIO 번호다.
UART0 RX에 COM/SiK의 TX 두 개를 동시에 구동하지 않는다. USB CDC 대신 GPIO UART0를 사용한다.

## 2. 세 종류의 펌웨어를 분리한 이유

보드에는 아래 중 하나만 업로드한다. 여러 `setup()/loop()`를 같이 실행하지 않는다.

| PlatformIO 환경 | 진입 파일 | 용도 | UART0 |
|---|---|---|---:|
| `yd_esp32_s3` | `src/main.cpp` | 설정 파일의 센서로 생산 FSM | 57600 |
| `yd_esp32_s3_tcs34725` | 같은 파일 | TCS34725 강제 지정 생산 FSM | 57600 |
| `robot_bench` | `src/bench_main.cpp` | 저출력 모터·수동·데이터·비전 시험 | 57600 |
| `robot_bench_tcs34725` | 같은 파일 | TCS34725 벤치 | 57600 |
| `sensor_serial_test` | `src/sensor_serial_test.cpp` | 설정 파일의 센서 원시값만 확인 | 115200 |
| `sensor_serial_test_tcs34725` | 같은 파일 | TCS34725 원시값만 확인 | 115200 |

생산 환경은 벤치 컨트롤러를 빌드하지 않는다. 벤치는 생산 FSM 메인을 실행하지 않는다.
센서 전용은 모터·버튼 ISR·시스템 안전관리도 실행하지 않는다.
**센서 전용 시험에서는 모터 전원을 물리적으로 분리한다.**
`platformio.ini`의 source filter가 진입점을 나누며 공용 센서/모터 코드를 복제하지 않는다.

## 3. 파일을 나눈 의도와 책임

`include/경로.hpp`는 공용 API·자료형, `src/경로.cpp`는 실제 구현이다.
설정은 `constexpr` 중심이다. ISR에서는 플래그와 즉시 EN 차단만 수행한다.
모든 모듈이 각자 운전 허용 상태를 만드는 구조를 피했다.

| 파일 / 모듈 | 만든 이유와 실제 책임 |
|---|---|
| `platformio.ini` | 플랫폼/보드/라이브러리 버전 고정, 진입점 선택. 현재 8MB DevKitC, PSRAM 미사용 |
| `include/pins.hpp` | V1 배선의 유일한 코드 기준. ISR EN 마스크도 이 정의 사용 |
| `include/config.hpp` | UART 속도·신선도·버튼·LED·로그의 공통 시간/용량 |
| `include/robot_types.hpp` | 안전·센서·비전 스냅샷, FSM 상태, 주행 의도, 모터 명령 연결 자료형 |
| `src/main.cpp` | 생산 실행 순서 연결. 레지스터/PWM 계산은 직접 구현하지 않음 |
| `app/boot_manager` | 초기 핀 안전부터 필수 모듈 초기화까지 순서 보장, 필수 모터 실패 시 구동 금지 |
| `hardware/board_io` | 부팅 초기에 PWM/EN LOW 설정, 일반 핀모드 초기화 |
| `hardware/reset_manager` | ESP 리셋 원인과 재무장 필요 플래그 제공. 자동 리셋은 실행하지 않음 |
| `interrupts/button_interrupts` | SW1 영구 래치, SW2 에지·디바운스·해제 이벤트, ESTOP 영구 루프 |
| `system/system_manager` | SW2 이벤트 단독 소비자. 운전 요청·교정·집계 고장을 합쳐 motorAllowed 결정 |
| `system/event_logger` | 번호/문자열 고정 큐, 변경·중복 억제, 일반 UART 쓰기 지연 |
| `system/status_led` | 주체별 요청 보존, 우선순위·TTL로 두 WS2812 표시 결정 |
| `sensors/color_sensor_types` | 모델·모서리·색·원시값·교정 기준·판정 결과와 출력 이름 |
| `include/sensors/sensor_config.hpp` | 모델, 수광·게인·조명, TCA 채널, 확정 횟수, 임시 임계값, 교정 여유 |
| `sensors/color_sensor_manager` | Wire/TCA/레지스터 담당. 수광 완료 확인과 새 원시 측정 발행 |
| `sensors/floor_color_classifier` | 원시값을 네 바닥색/Unknown으로 판별. I2C·UART·모터를 건드리지 않음 |
| `sensors/color_calibration` | 시작 전 UART 안내식 교정과 NVS 저장. 판별 알고리즘과 분리 |
| `sensors/sensor_manager` | 새 sequence만 판별, 3회 확정, 무효/오래된 판정 폐기, 오류 변경 기록, snapshot |
| `include/communication/vision_protocol.hpp` | 패킷·상태 비트·범위·오류번호. Pi 송신기와 맞춰야 하는 계약 |
| `communication/raspberry_link` | UART1 재조립, 헤더 재동기화, 중복 sequence와 영상 신선도 처리 |
| `include/control/control_config.hpp` | 생산 출력·중심 기준·공격/탈출 시간·위험색 마스크 |
| `control/robot_fsm` | 안전/바닥/비전으로 무엇을 할지 판단하고 DriveIntent 반환. GPIO 직접 제어 없음 |
| `control/drive_logic` | 의도를 좌우 MotorCommand와 80ms 기한으로 변환 |
| `include/motor/motor_config.hpp` | PWM·방향 반전·출력 상한·명령 만료·브레이크 전기 조합 |
| `motor/motor_controller` | 공용 API, 안전 검사, 제한, 뮤텍스, 만료 감시 태스크, 상태 반환 |
| `motor/bts7960_driver` | BTS7960 하나의 실제 PWM/EN 쓰기, 방향 전환 deadtime, 영구 금지 확인 |
| `src/bench_main.cpp` | 벤치 콘솔·안전·센서/비전·CSV 연결. 교정 콘솔은 실행하지 않음 |
| `bench/bench_controller` | MOTOR/MANUAL/DATA/ALIGN/FOLLOW/AVOID의 시간 기반 명령 생성 |
| `include/bench/bench_config.hpp` | 시험 출력/유지시간/추적·회피 조건. 생산 전략 설정과 분리 |
| `src/sensor_serial_test.cpp` | 모터를 건드리지 않고 100ms마다 버튼/센서 원시값 출력 |
| `tests/run_host_tests.ps1` | 실제 소스를 PC 가짜 하드웨어에 연결해 두 모델 컴파일/실행 |
| `tests/host/test_firmware.cpp` | 생산 모터·안전·FSM·UART·센서·교정·로그·메인 연결 회귀 시험 |
| `tests/host/test_bench.cpp` | 모드 시간·수동 만료·추적/회피·콘솔·벤치 메인 회귀 시험 |
| `tests/host/fake_hardware.cpp` 및 shim 헤더 | 가상 시간/GPIO/UART/I2C/NVS/태스크. 생산 알고리즘은 대체하지 않음 |

`ContactCheck`, `UndercutDrive`, `ScoreHold`, `WallEscape`, `StuckRecovery`, `Stop` 등
일부 `RobotState` 이름은 현재 생산 FSM에서 진입하지 않는 예약 상태다.
접촉·스포크 삽입·고착을 센서로 확인하는 기능이 있다고 해석하지 않는다.

## 4. 부팅과 메인 루프 워크플로우

```text
전원/리셋
  → PWM/EN LOW → 리셋 원인 → UART0 → 모터/PWM/만료 감시
  → 버튼 ISR → LED → 컬러 센서/NVS → UART1 → 시스템 관리자
  → 시작 대기
       ├─ CAL START → 48단계 측정 → CAL SAVE → 시작 대기
       └─ SW2 정상 눌림/해제 → Running

생산 loop()
  안전/버튼 → 라즈 수신 → 센서 짧은 I2C 단계 → 안전 재확인
  → 교정 콘솔 (교정 중이면 모터 정지, FSM 생략)
  → 센서/비전 snapshot → FSM 의도 → 좌우 명령 → 제한/PWM
  → LED → 이벤트 큐 출력 → delay(1)

독립 경로
  SW1 ISR → 영구 구동 금지 + EN 즉시 LOW
           → 일반 문맥 브레이크 → ESTOP만 3초마다 → 재부팅 필요
  모터 만료 태스크 → 마지막 명령 기한 확인 → 만료 시 브레이크
```

컬러 센서 초기화 실패는 부팅 실패로 만들지 않는다. 라즈도 필수 부팅 장치가 아니다.
모터 초기화/감시 태스크 생성 실패는 구동을 막는다.
각 `begin()`은 부팅용이며 운전 중 반복 초기화/자동 복구나 SW1 래치 우회용으로 호출하지 않는다.

## 5. 안전 조건과 의도된 예외

`SystemManager`는 **구동해도 되는지**, `RobotFsm`은 허용된 상태에서 **어떻게 움직일지** 결정한다.

| 상황 | 생산 펌웨어 | 벤치 펌웨어 |
|---|---|---|
| 전원 직후 | SW2 대기, 무구동 | STOP 모드, 무구동 |
| 부팅부터 SW2 눌림 | 첫 해제 무시, 새 눌림/해제 필요 | 동일 |
| 정상 SW2 눌림/해제 | Running, FSM 시작 | 선택 모드 허용 |
| SW2 다시 조작 | 정지 버튼이 아님 | 정지 버튼이 아님 |
| STOP/모드 변경 | API로 운전 요청 폐기 | STOP/MODE 콘솔, 새 SW2 필요 |
| 정지 전에 누른 SW2 해제 | 출발에 사용하지 않음 | 동일 |
| SW1 눌림 | 영구 정지, 해제해도 재부팅 전 금지 | 동일 |
| 라즈 없음/영상 오래됨 | 탐색/상실 처리, 짧은 공격은 지속 가능 | 추적 정지; AVOID 진행 중 탈출은 우선 |
| 센서 하나/전부 없음 | Unknown, 주행 시작 허용 | AVOID는 정지, 나머지 주행 모드는 가능 |
| 색 변경 후 3회 확정 중 | Unknown은 위험색이 아님 | AVOID는 Unknown 때문에 정지 |
| 센서 I2C/변환 고장 | 채널 제외, 재부팅 전 자동 초기화 없음 | 동일 |
| 무수광/포화 | 그 측정 무효, 채널 유지 | 동일 |
| 모터/애플리케이션 집계 고장 | 즉시 정지·운전 요청/버튼 제스처 폐기 | 동일 |
| 명령 만료 | 브레이크, 새 유효 명령은 적용 가능 | 동일 |

생산에서 Unknown 전체를 정지로 바꾸지 않은 것은 센서 부팅 실패에도 진행하라는 요구에 따른다.
따라서 생산은 센서 고장 시 바닥 회피를 보장하지 않는다. 시험 AVOID는 의도적으로 더 보수적이다.
`setSensorHealthy(false)` 집계 API는 있지만 개별 컬러 센서 실패에 자동 연결하지 않는다.
하드웨어 제동/출력 풀다운/전원 상실 중 안전은 소프트웨어만으로 보장하지 않는다.

## 6. 생산 FSM이 실제로 하는 일

```text
WaitStart → Search → TargetConfirm → TrackAlign / Approach
                                  → DiveReady(돌진 220ms)
                                  → DiveBrake(90ms)
                                  → SpokeEngaged(전진 350ms) → Push
                                                              ↓ 목표 상실
                                                  Backoff(260ms) → Search
어느 구동 단계든 확인된 위험색 → ZoneEscape
운전 금지 → WaitStart / EmergencyStop
```

- Search: 300 천분율 제자리 회전, 절대 시간 기준 1.2초마다 방향 변경.
- TargetConfirm: 서로 다른 새 목표 프레임 2회 필요. 확인 중에도 중앙이면 240으로 접근,
  벗어나면 회전한다. 정지한 채로만 확인하지는 않는다.
- TrackAlign: 중심 X=960, 오차 ±140 밖이면 회전280. 중앙이면 접근450과 비례 조향.
- 공격 진입: 확인 후 X 오차 ±75 이내, 박스 높이420 이상이면 시간 기반 공격 시작.
- DiveReady→DiveBrake→SpokeEngaged: 650 돌진, 브레이크, 480 삽입 전진.
  짧은 카메라 가림에도 진행하지만 SW1/위험색/운전 금지는 먼저 처리한다.
- Push: 650 전진과 작은 조향. 보이는 박스 높이210 미만 또는 X 오차600 초과이면 재확인.
  상실 시 마지막 **새 목표 프레임 시각**부터 500ms 이내만 직진 밀기 후 후진한다.
  앞의 공격이 시간을 소비했다면 유지 시간이 짧아지거나 바로 후진할 수 있다.
- 일반 목표 상실: 마지막 새 목표부터 260ms 이내는 마지막 방향 회전, 이후 Search.
- ZoneEscape: 빨강/노랑/파랑 위험. 전방이면360ms 후진, 후방이면 전진,
  이어 반대 방향 회전320ms. 여전히 위험하면 탈출 재판단.
  이동 방향에 새 위험이면 브레이크 한 번 후 방향을 새로 판단한다. 전후방 동시 위험은 정지한다.
  회전 단계는 현재 위험 방향을 반영하며, 위험이 없으면 짧은 예정 탈출 후 Search로 돌아간다.

박스 높이는 거리계가 아니며 스포크 삽입 성공을 확인하지 않는다.
`trackStable/multipleTargets/boxClipped`는 수신하지만 생산 공격을 모두 차단하는 조건은 아니다.
벤치 FOLLOW는 중앙 근처 잘린 박스에서 전진을 멈춘다. 전략의 세부 튜닝은 실물에서 진행한다.

## 7. 센서 수광과 새 측정 구분

네 센서는 순서대로 방문하지만 수광 자체는 독립적이다. 수광 시간을 delay로 기다리지 않는다.
각 Wire 거래는 동기식이고 최대5ms 타임아웃이 있으므로 전체 처리가 완전히 무대기는 아니다.
기본 I2C는400kHz다.

AS7341은 부팅 때 F2/F3/F5/F6/F7/Clear를 ADC6개에 연결하고 연속 수광한다.
완료 AINT를 확인·해제한 뒤 ASTATUS부터 버스트 읽기한다. AVALID만 계속 읽어 동일 결과를
새 측정으로 세지 않는다. 최소 수광 간격도 확인한다. F1/F4/F8/NIR는 측정하지 않는다.
공통10칸 배열의 미사용 칸은0, 유색 featureMask는0x76, Clear는 밝기와 비율의 분모다.

TCS34725는 AEN 켜기→수광 대기 상태→유효 RGBC 읽기→AEN 끄기로 측정한다.
코드 INTEGRATION_MS는2.4ms를 올림한3ms이고 읽기 전1ms를 더 기다린다.
한 센서씩 최소1ms 슬롯에 방문하므로 재방문은 이상적으로4ms다.
TCS의 3회 확정 지연을 단순히2.4ms×3으로 계산하면 안 된다.

원시 sequence는 새 결과 발행 때 증가한다. SensorManager는 새 sequence만 판별하고
같은 색3회를 확인한다. 같은 snapshot을100번 읽어도 횟수는 늘지 않는다.
색 변경·무효·오래된 값은 이전 reliable 판정을 취소한다. 교정 변경도 확정 필터를 초기화한다.

readyMask는 통신 가능한 채널이며 색 신뢰도가 아니다. raw.valid, floor.reliable,
consecutiveMatches, timestampMs를 구분해서 읽는다.
오류번호0=None,1=Initialization,2=I2c,3=Timeout,4=Range.
I2C/Timeout은 채널 제외, Range는 현재 결과만 무효다.

## 8. 바닥센서 조정 — 2026-10-05

모든 값은 `include/sensors/sensor_config.hpp`에서 수정 후 다시 빌드한다.
자동 게인·자동 노출·센서 재초기화는 없다.

```cpp
#define COLOR_SENSOR_MODEL COLOR_SENSOR_AS7341
// TCS 차량이면 위 값을 COLOR_SENSOR_TCS34725로 변경
```

TCS 전용 환경은 빌드 옵션 `COLOR_SENSOR_MODEL=2`로 기본값을 덮어쓴다.

| 조정 항목 | 설정 / 현재 시작값 |
|---|---|
| AS 수광 | AS7341_EXPOSURE_US=5000, ATIME=0/ASTEP=1797, 약4998.44us |
| AS 게인 | AS7341_GAIN=X16, 선택 X0.5..X512 |
| AS 자체 LED | AS7341_LED_ENABLED=true, LED_CURRENT_MA={20,20,20,20} |
| AS LED 전류 | 4..150mA 짝수, 모듈 LED가 AS LDR에 연결된 경우만 적용 |
| AS 내부 보정 | AS7341_AUTOZERO_INTERVAL=255, 첫 수광 전 보정/시작 지연 |
| TCS 수광 | TCS34725_INTEGRATION=Ms2_4, 선택2.4/24/50/101/154/614ms 계열 |
| TCS 게인 | TCS34725_GAIN=X16, 선택 X1/X4/X16/X60 |
| TCS 조명 | 별도 LED 제어 API 없음, 모듈 배선 확인 필요 |
| 확인 횟수 | COLOR_CONFIRM_COUNT=3, 3 미만 빌드 거부 |
| 신선도 | SAMPLE_STALE_MS, AS255ms / TCS253ms 기본 |
| 무교정 검정 한계 | 센서별 AS Clear180 / TCS Clear120 배열 |
| 무교정 유색 | 빨강 우세1.20, 파랑1.18, 노랑/파랑1.30, R/G0.55..1.80 |
| 교정 여유 | DEFAULT_RATIO_MARGIN_PERMILLE=150 / BRIGHTNESS=300 =15/30% |
| 교정 매칭 | 최소 비율폭.005, 최대점수1.0, 타색 점수차.08 |
| 밝기 가중치 | MATCH_COLOR_BRIGHTNESS_WEIGHT=.20 / BLACK=.55 |

무교정은 Clear 검정 한계 이하부터 검정으로 보고 나머지는 비율로 유색 판별, 애매하면 Unknown이다.
교정은 센서별 각 색의 세 자세 중 가까운 기준을 선택한다. 비율 허용 폭은 평균×여유,
3×표준편차, 최소폭 중 큰 값이다. 밝기는 min/max에 여유를 더한다.
타색과 너무 비슷하거나 점수가 나쁘면 Unknown이다. 같은 색의 다른 자세는 경쟁 색으로 세지 않는다.

### 반드시 유지할 실제 기체 조건

- 추가 가림막/구조물 없이 로봇 밑 그늘에서 자체 LED로 바닥을 비춘다.
- 10mm 단차 때문에 센서 간격은 근접3mm / 내려간 상태10mm / 걸친 상태20mm다.
  20mm 조건을 제거하거나 고정 높이로 가정하지 않는다.
- 3mm 포화, 20mm 약한 유색의 검정 오인, 경계 혼합색을 각각 확인한다.
- V1은 높이를 측정하지 않는다. matchedPose는 가까운 교정 기준이며 실제 높이/IMU 측정값이 아니다.
- 검정 바닥·공중·상대 로봇 표면을 항상 구분할 수 없다.
- 다음 개발자도 이 조건과 미검증 사항을 사용자에게 짚어준다.

조정 순서: 원시값→3mm 포화 방지→20mm 유색 신호 확인→필요시 수광 연장→세 높이 교정
→낮은 출력 경계 시험. 수광/게인/조명/채널 변경은 설정 서명을 바꾸므로 이전 NVS 교정 대신
임시 임계값을 사용한다. 자동 NVS 재작성이나 재교정은 하지 않는다.

## 9. 컬러 교정 사용법

**생산 펌웨어** 시작 대기 중 UART0 57600에서 실행한다. 벤치는 NVS를 불러오지만 교정 콘솔은
실행하지 않는다. 센서 전용도 교정이 없다. 네 채널 모두 초기화돼야 CAL START를 받는다.
SW1 래치 후에는 교정도 불가능하다. LF/CRLF 줄바꿈, 소문자는 대문자로 변환한다.

```text
CAL START
READY
# 준비3초 + 측정3초. 주석은 보내지 않는다.
ACCEPT
# 다음 배치 안내에 맞춰 READY→ACCEPT 반복
CAL SAVE
```

순서는 S1 빨강→노랑→파랑→검정, 각 색마다 Level→Lifted→Pressed, 이어 S2/S3/S4다.
4×4×3=48단계, 간격 안내10/20/3mm는 사람이 맞춘다. 준비/측정만 최소288초, 배치/응답은 추가다.
IMU는 사용하지 않는다. 유효한 새 측정으로 평균·표준편차·Clear min/max를 구한다.

| 명령 | 조건 / 의미 |
|---|---|
| CAL START | 운전 전 새 교정, 기존 저장 기준은 SAVE 전까지 유지 |
| READY | 배치 완료 후 준비/측정 |
| ACCEPT | 결과 수락, 다음 단계 |
| RETRY | 현재 결과 폐기, 다시 READY 대기 |
| BACK | 배치 대기/결과 확인 중 이전 단계 |
| STATUS / CAL STATUS | 상태·센서·색·자세·샘플 수·여유 표시 |
| CAL MARGIN 20 40 | 교정 중 비율20% / 밝기40% 여유, 두 정수1..100만 허용 |
| ABORT | 작업 중단, 기존 저장 교정 유지 |
| CAL SAVE | 전체 완료 후 NVS 저장, 실패는 오류 후 수동 재시도 가능 |
| CAL ERASE | 운전 전 저장 기준 삭제, 임시 기준 전환 |

3초 내 유효5샘플 미만이면 그 단계를 재안내한다. 긴 수광은 측정 시간도 조정한다.
NVS color-cal/data 한 블롭의 길이·버전·모델·설정 서명·유한값을 확인한다.
저장/삭제 실패 시 기존 RAM 기준을 보존한다. SAVE 전 중간 측정은 재부팅하면 사라진다.
교정 중 SW2는 교정을 중단하고 제스처를 버린다. 완전히 놓은 뒤 새로 눌렀다 놓아야 출발한다.

## 10. 라즈 UART 규격과 수신 의미

UART1 115200/8N1, CRC 없음, 고정14바이트, 16bit는 little-endian이다.
좌표는1920×1080 기준. 다른 영상 크기는 송신 측에서 변환해야 한다.

| 바이트 | 내용 |
|---:|---|
| 0..3 | AA 55 01 0A: 헤더/버전/payload 길이 |
| 4 | 새 처리 프레임 sequence, 255→0 순환 |
| 5 | 상태 비트 |
| 6..7 / 8..9 | 중심 X/Y, 0..1919 / 0..1079 |
| 10..11 / 12..13 | 박스 폭/높이, 목표 시1..1920 / 1..1080 |

bit0=TargetValid,1=TrackStable,2=MultipleTargets,3=BoxClipped,4=CameraOk,5=PipelineOk.
bit6/7은0. 목표 유효면 camera/pipeline도 유효해야 한다.
목표가 없으면 좌표/폭/높이와 bit1/2/3도0. 정상 카메라에서 목표만 없으면 flags0x30이다.

sequence1, flags0x31, 중심(960,540), 폭100/높이200 예:

```text
AA 55 01 0A 01 31 C0 03 1C 02 64 00 C8 00
```

한 루프 최대128바이트, 손상 후보 안의 다음 헤더 보존, 부분 입력20ms 끊김은 폐기.
정상 패킷/새 영상 수명은 각각120ms다. 동일 sequence/내용 재전송은 링크만 갱신하고
영상 수명을 늘리지 않는다. 같은 sequence/다른 내용은 오류다.
링크 끊김 후 첫 정상 패킷은 새 기준으로 받아 라즈 재부팅/sequence 초기화를 허용한다.
sequence 차이 크기로 역순/손실을 엄격 판정하지는 않는다.

50Hz는 송신 측 요구다. ESP가 그 주기를 만들거나 재전송을 요청하지 않는다.
14×50×10bit=7000bit/s로115200bps 대역 안이다. CRC가 없으므로 정상 형식의 비트 손상은
검출 보장이 없다. 현재 Pi JSON을 UART1에 그대로 넣으면 동작하지 않는다.

## 11. 공용 모터 API

일반 태스크/루프에서 MotorController를 사용하고 ISR에서 호출하지 않는다.
setTank는 좌우 독립, setArcade의 양의 steering은 왼쪽 출력 증가=오른쪽 선회다.
방향 반전은 motor_config.hpp에서만 설정한다.

```cpp
#include "motor/motor_controller.hpp"
#include "system/system_manager.hpp"

// 기존 부팅과 안전 update가 실행되는 일반 루프 안에서:
const SafetyStatus safety = SystemManager::safetyStatus();
MotorController::setTank(150, 150, safety); // 15%, 기본100ms
const MotorControllerStatus motor = MotorController::status();
// appliedLeftPermille: 제한 적용 후 논리 출력
// lastResult: Accepted / SafetyBlocked / CommandExpired 등
```

이 코드를 생산 main에 덧붙이면 FSM과 경쟁한다. 실행 모드당 명령 생성자가 한 곳이 되게 연결한다.
caller가 임의 Running 안전 스냅샷을 꾸며서 우회하지 않는다.

- 단위 -1000..1000 천분율, 생산 기본±650, 벤치±200.
- setOutputLimit 변경은 기존 출력을 정지한다. 새 명령이 필요하다.
- forward/reverse/rotateLeft/rotateRight, stop/coast/brake, status/outputLimit 제공.
- timeoutMs=0은 기본100ms. INT32_MAX 초과는 InvalidArgument와 브레이크로 거부한다.
- FSM/벤치 기한80ms. 직접 기한을 만들면 미래 간격은 INT32_MAX 이하로 사용한다.
  millis 순환으로 기한0이 된 경우도 실제 명시 기한으로 처리한다.
- 만료는 정지일 뿐 보드 리셋/영구 고장이 아니다. 다음 새 유효 명령은 적용 가능하다.
- requested는 마지막 요청, applied는 제한/정지 후 값. 정지 후에도 요청값은 남을 수 있다.
  outputsActive=false는 구동 명령이 없다는 뜻이지 브레이크 EN도 반드시 LOW라는 뜻은 아니다.
- 모터 API는 뮤텍스 보호. sensor/FSM/logger/system은 현재 메인 문맥용으로
  추후 여러 태스크에서 자동으로 thread-safe하다고 가정하면 안 된다.

PWM20kHz(50us)/8bit(0..255), 방향 전환 deadtime100us.
기본 브레이크 BothPwmLowEnableHigh는 실측 전 선택값이다.
SW1 ISR EN 차단 후 일반 문맥에서 선택한 브레이크를 적용·유지한다.
clearEmergencyStop은 일반 래치만 안전 조건에서 해제하며 실제 SW1 영구 래치는 해제하지 못한다.

## 12. 로그와 LED

일반 UART0 57600 로그 형식:

```text
EV,시간ms,이벤트번호,심각도,소스,value1,value2[,문자열]
```

심각도 D/I/W/E/F, 소스 SYS/STATE/SAFE/MOTOR/SENSOR/COM/USER.
100번대 부팅/시스템,200 상태/모드,300 통신,400 센서,500 모터,600 안전,900 사용자.
같은 번호·소스·value1·문자열은 기본1초 제한. value2는 반복 키에서 제외한다.
상태/모드/오류는 변경 API로 바뀔 때만 기록. 큐32개, 한 번 최대2개, 송신 공간 부족은
다음 루프로 미룬다. 큐가 차면 드롭, status().dropped로 확인하며 주행을 막지 않는다.

```cpp
#include "system/event_logger.hpp"
#include "system/status_led.hpp"

EventLogger::log(EventId::InvalidPacket, 6);
EventLogger::logText(900, LogSeverity::Info, LogSource::User, "test_begin");
EventLogger::faultChanged(LogSource::Sensor, FaultCode::Range, true, 1);
StatusLed::setBoth(LedOwner::User, LedState::Tracking, 500);
```

LED 요청은 즉시 WS2812를 쓰지 않고 update에서 최소20ms마다 반영한다.
내장 밝기32/255, 외부64/255, 대상별/주체별 요청 하나씩 유지한다.
높은 상태 우선순위가 이기고 같은 우선순위는 최신 요청, clear(owner)는 그 주체만 제거한다.
TTL=0은 계속 유지, 짧은 TTL 만료 후 다른 요청이 다시 표시된다.

| 우선순위 | 표시 |
|---:|---|
| 255/240/230/220 | ESTOP 빨강 / 일반 고장 빨강·흰색 / 모터 빨강·주황 / 센서 노랑 점멸 |
| 200/190/180 | 구역 주황 / 벽 자홍(예약) / 상실 보라 점멸 |
| 150/140/130/120 | 돌진 흰색 점멸 / 밀기 파랑 / 정렬 노랑 / 추적 초록 |
| 110/100/70/50/40 | 접근 청록 / 탐색 빨강 점멸 / 준비 파랑 / 대기 주황 / 부팅 파랑 점멸 |

개별 센서 오류 로그가 자동으로 전체 SensorFault LED를 만들지는 않는다.
벤치는 생산 FSM LED 갱신이 없으므로 시스템 대기/Ready 표시가 중심이다.
CAL 안내와 벤치 ACK/HELP는 사람이 요청한 동기 콘솔이며 일반 이벤트 큐와 다르다.
SW1 영구 루프 진입 후 일반 큐를 버리고 ESTOP만3초마다 출력한다.

## 13. 현재 주기와 스케줄링

| 처리 | 실행 방식 | 시간의 의미 |
|---|---|---|
| Arduino loop | 기본 loopTask 우선순위1, 코어는 Arduino 설정 | 매 반복 delay(1), 전체1kHz 보장은 아님 |
| 버튼 | ISR + 루프 디바운스 | SW1 즉시 래치, SW2 눌림/해제 각각40ms |
| 모터 만료 | FreeRTOS 태스크 우선순위2 | 5ms 간격, 실제 제동 지연은 실측 |
| 센서 방문 | 메인 최소1ms 슬롯 | AS 매번4개, TCS1개. 샘플 Hz와 다름 |
| AS 수광 | 내부 연속 약5ms | 이론 약200회/s, I2C/보정/누락으로 실제 낮아질 수 있음 |
| UART1 | 메인 제한 처리 | 송신 목표50Hz, 프레임 신선도120ms |
| FSM/명령 생성 | 교정 아닌 메인 반복 | 별도 고정주기 태스크 아님 |
| LED | 최소20ms | 최대 갱신 시도50Hz, 변경색만 전송 |
| 이벤트 | 루프 끝 최대2개 | 사건/변경 시 기록, 낮은 처리 순서 |
| 벤치 데이터 | 100ms마다5행 시도 | 최대10Hz, 80ms 내 못 보내면 프레임 생략 |
| 센서 전용 출력 | 약100ms | 약10Hz, 수광 주기와 다름 |

FreeRTOS는 Arduino 내부에도 사용된다. 직접 분리한 기능 태스크는 모터 만료뿐이다.
I2C·FSM·UART·교정·로그가 모두 독립 태스크라는 의미는 아니다.
I2C가 밀리면 만료 감시가 모터를 정지할 수 있고 다음 새 명령으로 다시 적용된다.
0.5m/s에서 순수5ms 수광 이동은2.5mm다. 색 변경 직후 혼합된 첫 결과를 버리는 이상적 모델의
3회 확정은 약20ms/10mm이지만 최대 반응거리 보장이 아니다.
초기 보정·폴링/읽기 지연·측정 누락·경계 혼합·제동거리는 별도다.

## 14. 빌드·업로드·실물 시험 순서

PlatformIO CLI 또는 VS Code PlatformIO가 필요하다. 플랫폼 espressif32 6.11.0,
Arduino core2.0.17, NeoPixel1.15.5. 실제 보드 플래시/전원/포트는 따로 확인한다.

```powershell
cd D:\C_ROBOT\ESP_MAIN
pio run -e robot_bench
pio run -e robot_bench -t upload
pio device monitor -e robot_bench -b 57600
# 필요하면 upload에 --upload-port COM번호, monitor에 -p COM번호 추가
```

1. 모터 전원 분리→sensor_serial_test 업로드→UART0 115200에서 네 센서/SW 원시값 확인.
2. 바퀴 띄우기→robot_bench 업로드→UART0 57600, 전원 직후 무구동 확인.
3. MODE MOTOR→SW2→좌/우 정역 각3초(12%), 사이0.5초 정지 확인.
4. SW1 차단·브레이크·ESTOP·해제 후 미복구 확인. 다음 시험은 재부팅.
5. MODE MANUAL→SW2→DRIVE 100 100 등을250ms보다 빠르게 반복, STOP/입력 상실 정지 확인.
6. 생산 환경으로 수광/게인 조정·교정 저장 후 벤치로 돌아와 NVS 기준 사용.
7. 규격 송신기 연결 후 ALIGN→FOLLOW→AVOID. 처음 두 모드는 바닥 보호가 없다.
8. 낮은 생산 출력으로 회피/비전 분리 시험 후 공격 시간/출력 조정.

벤치는 대문자·줄바꿈 필수. MODE는 기존 출발/수동 명령 폐기, DATA는 SW2 없이 무구동 출력.
HELP는 정지 후 도움말, STATUS는 지속 로그 켜기, LOG OFF로 끈다.
잘못된/긴/250ms 미완성 줄은 정지 후 줄 끝까지 버린다. 교정 명령은 받지 않는다.
정확한 명령·CSV·각 모드 조건은 [BENCH_TESTS.md](BENCH_TESTS.md)를 읽는다.

## 15. 검증 재실행과 한계

```powershell
cd D:\C_ROBOT\ESP_MAIN
.\tests\run_host_tests.ps1
.\tests\run_host_tests.ps1 -Bench
.\tests\run_host_tests.ps1 -Demo
pio run -e yd_esp32_s3 -e yd_esp32_s3_tcs34725 -e sensor_serial_test -e sensor_serial_test_tcs34725 -e robot_bench -e robot_bench_tcs34725
cd D:\C_ROBOT
.\.venv\Scripts\python.exe -m unittest discover -s tests -v
```

PC 펌웨어 시험은 PATH의 native g++ 또는 PlatformIO toolchain-gccmingw32가 필요하다.
실제 setup/loop와 모듈을 연결해 시간 순환·채터링·ISR 경합·UART 무작위 입력·센서 고장·
교정 저장 실패·만료·공격/벤치 콘솔을 시험한다. .pio/host-tests 결과는 Git에서 제외한다.
이번에는 정지 중 버튼/새 진행 방향 위험/교정 숫자 검사의 실패를 먼저 재현하고 수정했다.

최신: 생산 AS12그룹/4,994 검사, TCS12그룹/4,555 검사, 벤치 각각67 검사,
여섯 ESP32 빌드, Python 핵심5테스트 통과. 반복 assert는 독립 시나리오 개수가 아니다.
라즈 두 추적기는 로컬 파일20프레임씩 실행했다. GUI·실제 카메라·ESP 동시성·광학/전기 성능은
이 시험으로 증명하지 않는다. 보조 UI/영상 변환/CAD의 전체 경로도 실물 검증 범위 밖이다.

상세 검토/실물 목록은 [VERIFICATION.md](VERIFICATION.md), 다음 개발 기준은
[AGENTS.md](AGENTS.md), 영상 코드 설명은 [루트 README](../README.md)를 읽는다.
공격 전략의 세부 루틴은 실제 차량에서 튜닝하는 다음 단계다.

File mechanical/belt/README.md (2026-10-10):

# 벨트 구동계 도면과 계산

2026-10-10 기준 기구 설계 기록이다. 이 폴더의 현재 STEP은 형상 검토용이며 제작 승인본이 아니다.

## 공통 조건

- HTD5M, 피치 5mm
- 20T 풀리 두 개
- 풀리 피치원 지름: 31.83099mm
- 벨트 폭: 15mm
- 아이들러: 608 계열, 내경 8mm, 외경 22mm, 폭 7mm
- 아이들러 축: M8 볼트
- 단순 표시용 벨트 두께: 1mm

같은 20T 풀리 두 개의 무아이들러 피치 길이는 다음과 같다.

```text
L = 2C + 20 * 5
  = 2C + 100mm
```

따라서 중심거리 79mm는 258mm, 중심거리 129mm는 358mm다. 실제 구매품은 각각 260mm와 360mm이며,
아이들러로 약 2mm의 경로 증가와 초기 장력을 만든다.

## 모터-전륜 260mm 구간

위 풀리 중심 기준으로 아래 값을 사용한다.

| 항목 | 값 |
|---|---:|
| 풀리 중심거리 | 79mm |
| 이론적 260mm 아이들러 중심 | 왼쪽 18.249mm, 아래 36mm |
| 기존 직선 피치선에서 아이들러 중심까지 | 2.334mm |
| Ø22 베어링의 기하학적 누름량 | 8.666mm |
| 추천 슬롯 | 폭 9mm, 전체 길이 16mm |
| 슬롯 중심 이동량 | 7mm |
| 슬롯 중심 범위 | 왼쪽 17~24mm |

`17mm` 방향은 아이들러를 풀리 중심선 쪽으로 넣어 장력을 증가시키고, `24mm` 방향은 바깥쪽으로 빼서
벨트 장착 여유를 만든다. 실제 벨트 공차와 풀리 형상 때문에 이론점 하나로 구멍을 고정하지 않는다.

## 파일

- `belt_260_corrected_18.249x36.dxf`: 이론적 260mm 위치의 1mm 단순 벨트 외형
- `belt_260_pitchline_check.dxf`: 길이 260mm 피치선만 분리한 확인용 도면
- `belt_requested_13x36_263.23mm.dxf`: 왼쪽 13mm, 아래 36mm 위치의 비교 도면
- `belt_260_layout.svg`: 두 위치 비교 그림
- `idler_slot_dimension.svg`: 베어링 중심, 누름량과 슬롯 치수 그림
- `idler_slot_M8_9x16.dxf`: 추천 M8 슬롯 외형
- `motor_front_belt_current_review.step`: 사용자가 만든 최신 검토본

왼쪽 13mm, 아래 36mm 위치는 피치선 기준 약 263.23mm를 요구하므로 260mm 벨트를 팽팽하게 설치할 수
없다. 아래 36mm를 유지할 때 이론점은 왼쪽 약 18.249mm다.

최신 STEP에서 직접 추출한 값은 다음과 같다.

- 풀리 축간거리 79mm
- 아이들러 중심: 가로 17.9255mm, 위 풀리에서 아래 35mm
- 풀리 쪽 입력 원: Ø31.183mm
- 단순 벨트 두 경계: 약 257.976mm와 264.259mm
- 단순 형상 중앙선: 약 261.117mm
- 올바른 Ø31.831mm 피치원으로 같은 중심을 재계산한 경로: 약 260.169mm

현재 STEP의 Ø31.183mm가 피치원을 뜻했다면 숫자 순서 오류이므로 Ø31.831mm로 고친다. 또한 Ø22
베어링의 표면은 R11이므로 실제 벨트 외형은 베어링 바깥쪽 R11~R12에 있어야 한다. 현재 R10~R11
형상은 베어링 안쪽으로 들어가므로 물리 간섭 검토용으로 사용하지 않는다.

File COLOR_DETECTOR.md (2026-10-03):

# 초록색 상대 로봇 검출기

## 실행

프로젝트 루트 `D:\C_ROBOT`에서 실행한다.

```powershell
.\.venv\Scripts\python.exe scripts\color_detector_ui.py
```

기본 입력은 `dataset\videos\irc_highlight_1080p50.mp4`이다.

기본 실행은 단계별 튜닝 UI이다. 화면은 다음 세 창으로 분리된다.

- `Green detector tuning wizard`: 원본, 현재 마스크, 단계별 가이드
- `1 Playback`: 영상 위치
- `2 Current stage controls`: 현재 필터에 필요한 슬라이더만 표시

영상은 초록 원통이 보이는 92% 지점에서 일시정지된 상태로 시작한다.

기존 전체 설정 UI가 필요하면 다음처럼 실행한다.

```powershell
.\.venv\Scripts\python.exe scripts\color_detector_ui.py --advanced-ui
```

## 시험 영상 다시 만들기

```powershell
.\.venv\Scripts\python.exe scripts\prepare_test_video.py
```

원본은 1280x720 29.97FPS이므로 출력의 추가 프레임은 타임스탬프에 맞춰 반복된다. 이 영상은 1080p 처리 부하와 UI 시험용이며, 실제 Camera Module 3 Wide의 세부 묘사를 재현하지 않는다.

## 단계별 튜닝 순서

1. BGR의 G-R, G-B 차이
2. ExG (`2G-R-B`)
3. HSV 초록색 범위
4. Lab 초록색 범위
5. 네 방식 중 3개 이상이 동의한 픽셀 유지
6. 타원형 3x3 Closing 1회
7. 최대 2개 후보의 면적, 채움률, 색상 신뢰도 조정
8. 최종 영상 확인 및 설정 저장

기본 융합 방식은 `Vote 3`이다. `Core+Support`는 더 넓은 색 영역을 복원하지만 장면이 복잡하면 느려질 수 있다.

## 융합 모드

`Fusion 0-8` 트랙바를 사용한다.

| 값 | 방식 |
|---:|---|
| 0 | BGR |
| 1 | ExG |
| 2 | HSV |
| 3 | Lab |
| 4 | OR |
| 5 | AND |
| 6 | Vote 2 |
| 7 | Vote 3 |
| 8 | Core+Support |

## 스무딩 모드

`Smooth 0-3` 트랙바를 사용한다.

| 값 | 방식 |
|---:|---|
| 0 | 없음 |
| 1 | Gaussian |
| 2 | Median |
| 3 | Bilateral |

기본값은 스무딩 없음이다.

## 단계형 UI 키보드

| 키 | 동작 |
|---|---|
| `[` / `]` | 이전/다음 튜닝 단계 |
| M | 재생 모드와 단일 필터 튜닝 모드 전환 |
| Space | 재생 또는 일시정지 |
| N | 다음 프레임 |
| P | 이전 프레임 |
| 마우스 드래그 | 초록 원통 자동 튜닝 영역 선택 |
| A | 현재 BGR/ExG/HSV/Lab 필터 자동 튜닝 |
| C | 자동 튜닝 영역 삭제 |
| S | 원본, 결과, 모든 마스크 저장 |
| W | 현재 설정 저장 |
| L | 저장한 설정 불러오기 |
| R | 기본 설정 복원 |
| B | 벤치마크 기록 시작 또는 종료 |
| E | 전체 9분할 분석 영상 내보내기 시작 |
| X | 진행 중인 영상 내보내기 중단 |
| Q | 종료 |

현재 설정은 `config\color_detector_last.json`에 저장된다. 스냅샷과 벤치마크 CSV는 `output\color_detector` 아래에 저장된다.

메인 창 오른쪽의 `EXPORT FULL VIDEO` 버튼을 누르면 현재 슬라이더 설정으로 전체 영상을 만든다. `STOP EXPORT`는 진행 중인 출력을 중단하고, `SAVE SNAPSHOT`과 `SAVE SETTINGS`는 각각 현재 화면과 현재 설정을 저장한다. 영상 출력 중에도 UI에서 재생하거나 설정을 확인할 수 있다. 다만 출력 작업은 시작 시점의 설정 복사본을 사용하므로, 슬라이더를 바꾼 뒤에는 다시 출력해야 변경값이 반영된다.

## 모든 마스크 영상 출력

내보낸 영상은 1920x1080, 50FPS의 3x3 비교 화면이다.

| 위치 | 내용 |
|---|---|
| 왼쪽 위 | 원본 위 최종 검출 박스와 중심점 |
| 가운데 위 | 융합과 모폴로지를 마친 최종 마스크 |
| 오른쪽 위 | 최대 2개로 선택된 후보만 표시한 마스크 |
| 가운데 줄 | BGR, ExG+색 우세 조건, HSV 마스크 |
| 아래 줄 | Lab, 엄격한 공통 영역, 필터 투표 수 |

UI 없이 저장된 설정으로 직접 출력하려면 다음 명령을 사용한다.

```powershell
.\.venv\Scripts\python.exe scripts\color_detector_export.py --config config\color_detector_last.json --output output\color_detector\exports\green_detector_all_masks.mp4
```

영상과 함께 같은 이름의 `.json` 파일도 생성된다. 이 파일에는 사용한 입력 영상, 설정, 처리 시간과 출력 프레임 수가 기록된다.

자동 튜닝할 때는 녹색 원통을 가능한 한 여백 없이 마우스로 감싼 뒤 `A`를 누른다. 자동 계산 결과의 원통 유지율과 화면 바깥 흰색 비율이 가이드 아래에 표시된다. 자동 결과가 완벽하지 않으면 현재 단계의 작은 슬라이더 창에서 값만 조금씩 보정한다.

## UI 없이 벤치마크

```powershell
.\.venv\Scripts\python.exe scripts\color_detector_ui.py --benchmark --start-frame 12900 --max-frames 200
```

평균, p95, p99 처리시간과 50FPS, 30FPS, 24FPS 주기 초과 횟수를 출력한다.

## 라즈베리파이용 경량 검출

`scripts\color_detection_lightweight.py`에는 다음 순서의 경량 파이프라인이 구현되어 있다.

1. 1920x1080 입력을 960x540 탐색 영상으로 축소
2. 탐색 영상에서 BGR과 ExG를 한 번의 채널 분리로 계산
3. 초록색 후보를 최대 8개 ROI로 변환
4. 원본 해상도의 ROI 안에서만 BGR, ExG, HSV, Lab Vote 3 재검증
5. 기존과 같은 후보 조건으로 최대 2개 선택

기존 방식과 경량 방식을 같은 프레임으로 비교하려면 다음 명령을 사용한다.

```powershell
.\.venv\Scripts\python.exe scripts\benchmark_lightweight_compare.py --start-frame 12900 --max-frames 200
```

영상 전체를 일정 간격으로 표본 검사하려면 다음처럼 실행한다.

```powershell
.\.venv\Scripts\python.exe scripts\benchmark_lightweight_compare.py --start-frame 0 --max-frames 200 --frame-step 70
```

비교 결과 CSV와 JSON은 `output\color_detector\benchmarks`에 저장된다. 속도뿐 아니라 검출 유무 일치율, 후보 개수 일치율, 중심점 거리, 선택 마스크 IoU도 함께 기록한다.

현재 PC에서 저장된 튜닝값으로 측정한 결과는 다음과 같다. 이 수치는 Raspberry Pi 5 실측값이 아니라 두 알고리즘의 상대적인 연산량 비교다.

| 시험 | 기존 1080p 전체 처리 | 경량 ROI 처리 | 향상 |
|---|---:|---:|---:|
| 12900번부터 연속 200프레임 | 31.08ms, 32.18FPS | 8.11ms, 123.28FPS | 3.83배 |
| 전체 영상 70프레임 간격 200장 | 31.29ms, 31.96FPS | 7.50ms, 133.28FPS | 4.17배 |

두 시험 모두 기존 방식과 검출 유무 및 후보 개수가 100% 일치했고, 동시에 검출된 주 후보의 평균 중심점 오차는 0픽셀이었다. 최종 판단은 Camera Module 3 Wide가 연결된 Raspberry Pi 5에서 다시 측정해야 한다.

## Raspberry Pi 5에서 간단히 실행

라즈베리파이에는 프로젝트 폴더를 복사한 뒤 터미널에서 다음 명령만 실행한다.

```bash
cd C_ROBOT
bash setup_raspberry_pi.sh
./run_pi_tracker.sh
```

기본 설정은 Camera Module 3 Wide, 1920x1080, 50FPS, 960x540 탐색 스트림이다. 화면 표시와 영상 저장은 하지 않고 다음과 같이 표적 좌표만 출력한다.

```text
frame=120 process=9.42ms targets=2 #1 x=1041.2 y=451.8 area=3247 conf=0.96 #2 x=252.4 y=547.1 area=834 conf=0.93
```

검출 화면을 직접 보려면 다음처럼 실행한다.

```bash
./run_pi_tracker.sh --preview
```

로봇 프로그램에서 읽기 쉬운 JSON Lines 형식은 다음과 같다.

```bash
./run_pi_tracker.sh --json
```

출력이 너무 많으면 10프레임마다 한 번만 표시한다.

```bash
./run_pi_tracker.sh --print-every 10
```

실전에서는 `--preview`를 사용하지 않는 것이 가장 빠르다. 종료는 `Ctrl+C`를 누른다. 카메라 없이 PC 영상으로 같은 실행 파일을 시험할 수도 있다.

```powershell
.\.venv\Scripts\python.exe scripts\pi_green_tracker.py --source dataset\videos\irc_highlight_1080p50.mp4 --start-frame 13091 --max-frames 20
```

Windows에서 `--source`를 생략하면 기본 시험 영상 `dataset\videos\irc_highlight_1080p50.mp4`를 사용한다. 따라서 다음 명령만 실행해도 Picamera2 없이 영상 처리가 시작된다.

```powershell
.\.venv\Scripts\python.exe scripts\pi_green_tracker.py
```

검출 화면까지 보려면 `--preview`를 추가한다.

미리보기 창 아래의 `Time` 막대를 움직이면 원하는 영상 프레임으로 즉시 이동한다. 세팅 슬라이더는 표시되지 않는다. 영상 끝에서 다시 반복하면서 성능을 계속 보려면 다음처럼 실행한다.

```powershell
.\.venv\Scripts\python.exe scripts\pi_green_tracker.py --start-frame 12900 --preview --quiet --loop
```

미리보기 위쪽의 버튼과 단축키는 다음과 같다.

| 버튼 | 키 | 동작 |
|---|---|---|
| `MASKS OFF/ON` | M | 오른쪽에 Proposal, BGR, ExG, HSV, Lab, Core, Support, Fused, Cleaned, Selected 마스크 표시 |
| `EXPORT FULL` | E | 원본 영상의 처음부터 끝까지 마스크 화면을 포함한 MP4 하나로 자동 저장 |

전체 출력 파일은 `output\color_detector\exports`에 1280x720, 50FPS MP4로 저장된다. 버튼은 한 번만 누르면 되고 현재 재생 위치와 관계없이 0프레임부터 마지막 프레임까지 별도 작업으로 처리한다. 마스크를 켠 상태의 현재 PC 측정은 검출 평균 8.92ms, 화면 전체 반복 평균 19.65ms, 처리량 50.89FPS였다.

## 화면 표시 성능 비교

미리보기 화면에는 최근 60프레임 기준 검출 시간과 전체 화면 반복 FPS가 표시된다.

화면 없이 벤치마크:

```powershell
.\.venv\Scripts\python.exe scripts\pi_green_tracker.py --start-frame 12900 --max-frames 210 --warmup-frames 10 --benchmark --quiet
```

1280x720 검출 화면을 띄운 상태의 벤치마크:

```powershell
.\.venv\Scripts\python.exe scripts\pi_green_tracker.py --start-frame 12900 --max-frames 210 --warmup-frames 10 --benchmark --quiet --preview
```

현재 PC에서 동일한 200프레임을 측정한 결과다.

| 모드 | 검출 평균 | 전체 반복 평균 | 실제 처리량 | 20ms 초과 |
|---|---:|---:|---:|---:|
| 화면 없음 | 8.09ms | 11.95ms | 83.70FPS | 1회 |
| 1280x720 화면 표시 | 8.08ms | 16.28ms | 61.43FPS | 2회 |

화면 표시 때문에 평균 4.33ms가 추가됐지만 50FPS 처리 예산인 20ms 안에 들어왔다. 초기화 또는 영상 디코딩으로 생긴 단발성 지연도 초과 횟수에 포함된다. 결과 JSON은 `output\color_detector\benchmarks`에 저장된다.

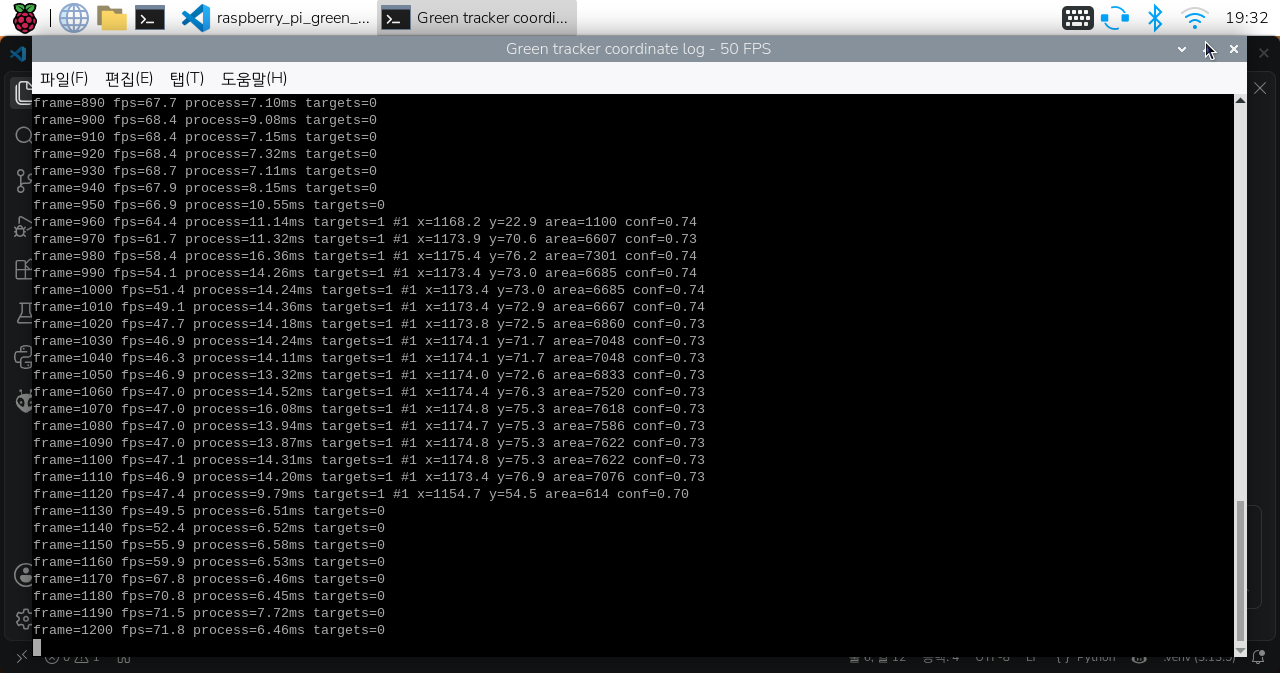
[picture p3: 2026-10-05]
pi-green-tracker-50fps.png

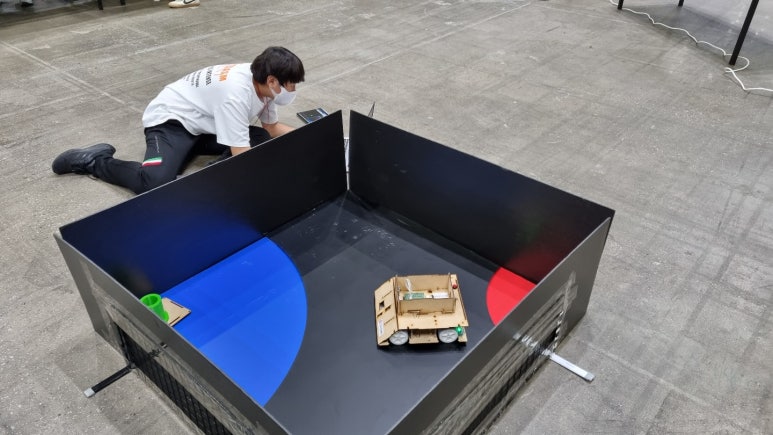
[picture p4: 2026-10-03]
img/KakaoTalk_20220726_033758780_18.jpg

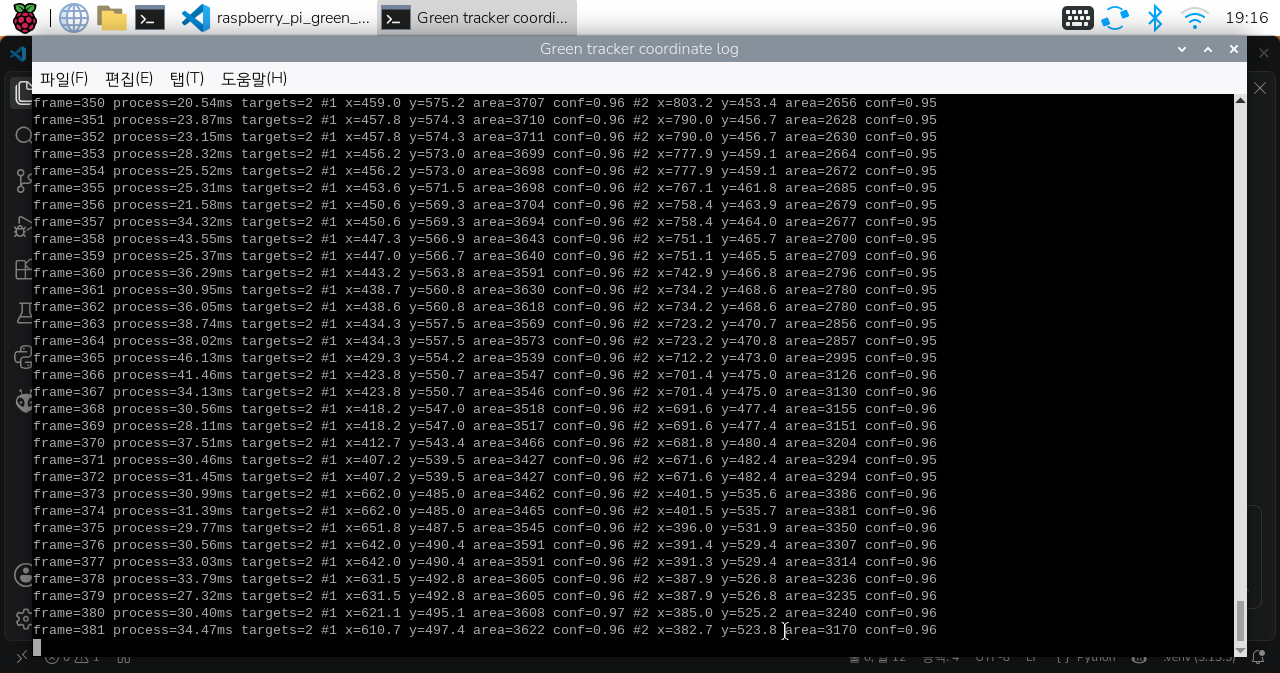
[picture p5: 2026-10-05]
pi-green-tracker-log.png

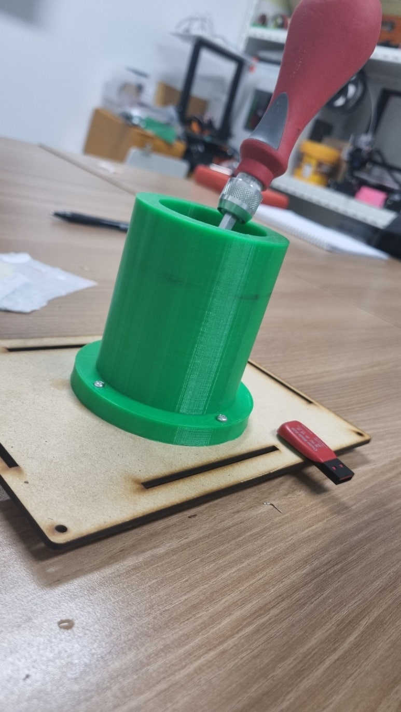
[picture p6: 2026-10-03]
img/KakaoTalk_20220726_033758780.jpg

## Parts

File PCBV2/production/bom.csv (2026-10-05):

Designator | Footprint | Quantity | Value | LCSC Part #
A1 | YD-ESP32-S3 | 1 | YD-ESP32-S3
C1, C2 | 0805 | 2 | 10uF
C3 | 0805 | 1 | 0.1uF
J1 | Molex_SPOX_5267-03A_1x03_P2.50mm_Vertical | 1 | IR1
J10, J9 | Molex_SPOX_5267-08A_1x08_P2.50mm_Vertical | 2 | Conn_01x08
J11 | Molex_SPOX_5267-04A_1x04_P2.50mm_Vertical | 1 | AS7341_1
J12 | Molex_SPOX_5267-04A_1x04_P2.50mm_Vertical | 1 | AS7341_2
J13, J16 | Molex_SPOX_5267-06A_1x06_P2.50mm_Vertical | 2 | Conn_01x06
J14 | Molex_SPOX_5267-04A_1x04_P2.50mm_Vertical | 1 | AS7341_3
J15 | Molex_SPOX_5267-04A_1x04_P2.50mm_Vertical | 1 | AS7341_4
J17 | Molex_SPOX_5267-02A_1x02_P2.50mm_Vertical | 1 | SW1
J18 | Molex_SPOX_5267-02A_1x02_P2.50mm_Vertical | 1 | SW2
J19, J20, J21 | Molex_SPOX_5267-04A_1x04_P2.50mm_Vertical | 3 | UART
J2 | Molex_SPOX_5267-03A_1x03_P2.50mm_Vertical | 1 | IR2
J3 | Molex_SPOX_5267-03A_1x03_P2.50mm_Vertical | 1 | IR3
J4 | Molex_SPOX_5267-03A_1x03_P2.50mm_Vertical | 1 | IR4
J5 | AMASS_XT30U-M_1x02_P5.0mm_Vertical | 1 | Conn_01x02
J6 | Molex_SPOX_5267-02A_1x02_P2.50mm_Vertical | 1 | Conn_01x02
J7 | Molex_SPOX_5267-03A_1x03_P2.50mm_Vertical | 1 | IR5
J8 | Molex_SPOX_5267-03A_1x03_P2.50mm_Vertical | 1 | IR6
R1 | 0603 | 1 | 100K
R10, R5, R6, R9 | 0603 | 4 | 470
R11, R13 | 0603 | 2 | 6.8K
R12, R14 | 0603 | 2 | 4.7K
R15, R16, R17, R2 | 0603 | 4 | 10K
R3, R4, R7, R8 | 0603 | 4 | 1K
U1, U2 | XL4015 | 2 | ~
U3 | SOT-223-3_TabPin2 | 1 | AMS1117-3.3
U4 | TSSOP-24_4.4x7.8mm_P0.65mm | 1 | TCA9548APWR
U5 | MPU6050 | 1 | ~

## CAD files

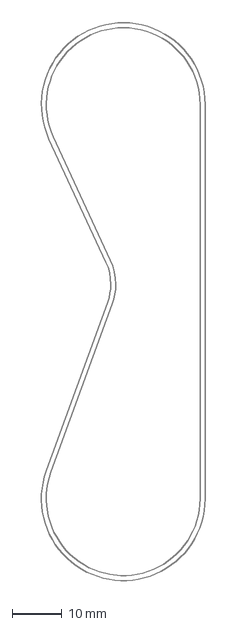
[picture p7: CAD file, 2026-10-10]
mechanical/belt/belt_requested_13x36_263.23mm.dxf
34.1 x 114.4 mm

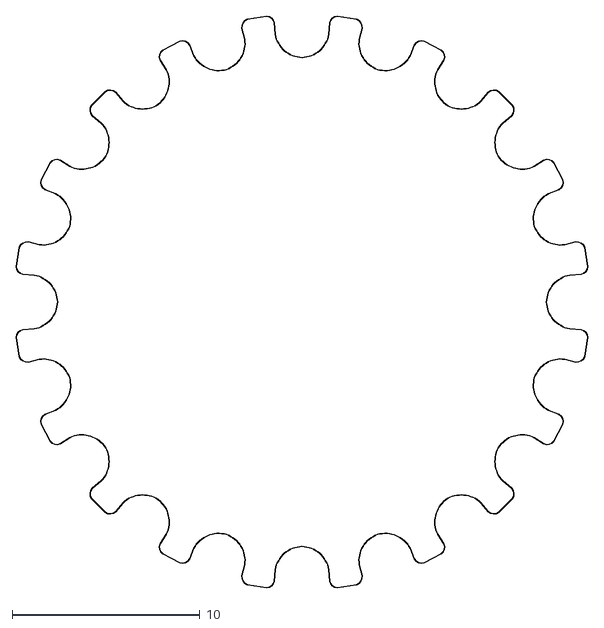
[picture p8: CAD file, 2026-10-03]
pulley_HTD_5mm_20.DXF
30.5 x 30.5

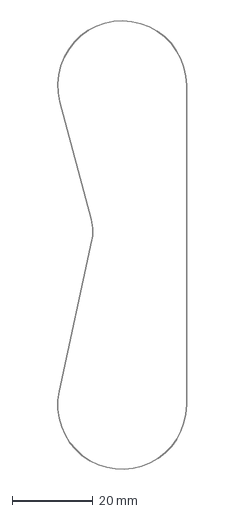
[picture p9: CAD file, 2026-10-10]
mechanical/belt/belt_260_pitchline_check.dxf
32.9 x 113.0 mm

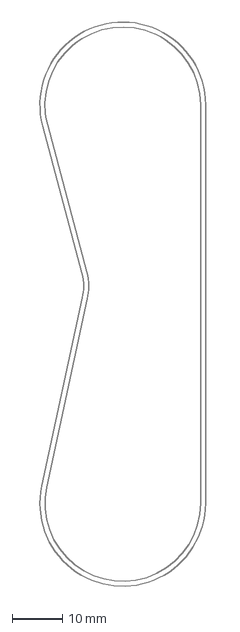
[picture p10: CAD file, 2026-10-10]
mechanical/belt/belt_260_corrected_18.249x36.dxf
33.9 x 114.1 mm

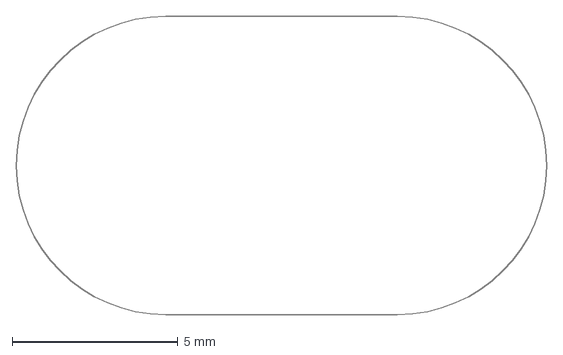
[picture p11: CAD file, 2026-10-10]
mechanical/belt/idler_slot_M8_9x16.dxf
16.0 x 9.00 mm

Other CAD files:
F608ZZ.step
PCBV2/C_ROBOT_PCB_3D.step
mechanical/belt/motor_front_belt_current_review.step

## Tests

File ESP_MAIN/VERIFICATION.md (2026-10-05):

# V1 펌웨어 요구사항·구조·검증 기록

검토일: 2026-10-05. 대상: `D:\C_ROBOT\ESP_MAIN`의 실제 소스.
하드웨어가 없는 상태에서 코드 수정, PC 자동 검증, ESP32 빌드를 실시했다.
아래의 통과는 시험한 입력과 조건에서의 결과이며 모든 하드웨어 동작을 보증한다는 뜻은 아니다.

## 최신 통합 검토 — 생산/벤치/영상 처리

2026-10-05 전체 펌웨어 연결부와 별도 센서·벤치 진입점을 재검토했다. 아래 결과를 과거 수치보다 우선한다.

- `requestStop()` 전에 누르기 시작한 SW2를 나중에 놓으면 재출발할 수 있었다.
  안정된 눌림과 아직 디바운스 중인 눌림 모두 시험으로 재현했다. 정지/집계 고장/교정 진입 시
  기존 제스처를 취소하며, 눌린 버튼은 안정된 해제 후 새 눌림·해제를 해야 한다.
- 생산 ZoneEscape가 최초 위험 비트만 사용해 새 후방 위험에도 후진했다. 시험으로 재현하고
  진행 방향의 새 위험은 한 번 브레이크 후 새 방향으로 판단하도록 수정했다. 전후방 동시 위험은
  브레이크를 유지한다. 회전 단계는 현재 확인된 위험 방향을 사용한다. 벤치도 회전 방향을 갱신한다.
- `CAL MARGIN`의 `%u` 입력이 뒤쪽 쓰레기 문자열이나 큰 정수의 넘침을 받아들일 수 있었다.
  잘못된 입력으로 교정 허용 범위가 바뀌는 시험을 재현했다. 이제 두 개의 1..100 정수만 허용한다.
- 잘못된 공개 벤치 모드 값은 STOP으로 정규화한다. 모터 API의 `timeoutMs > INT32_MAX`는
  시간 순환 비교가 불가능하므로 InvalidArgument와 브레이크로 거부한다.
- 일반 영상 추적 실행에서 FPS 목록이 계속 늘어나던 부분은 최근 60프레임만 보관하도록 했다.
  명시적 벤치마크의 전체 측정 목록은 보고서 생성을 위해 유지한다.

| 최신 검증 | 결과 |
|---|---|
| 생산 AS7341 / TCS34725 실제 소스 PC 시험 | 각각 12그룹, 4,994 / 4,555 검사 통과 |
| 별도 벤치 AS7341 / TCS34725 실제 소스 PC 시험 | 각각 67 검사 통과 |
| 생산 / 센서 전용 / 벤치 × 두 모델 | 여섯 PlatformIO 빌드 성공 |
| 생산 AS7341 / TCS34725 RAM | 각각 36,140 bytes |
| 생산 AS7341 / TCS34725 Flash | 342,049 / 341,609 bytes |
| 영상 핵심 알고리즘 | `tests/test_vision.py` 5개 테스트 통과 |
| Python 구문 검사 | scripts 및 루트 두 추적기, 테스트 통과 |
| 두 Pi 추적기 파일 입력 | 로컬 1080p50 영상 각각 20프레임, 화면 없이 정상 종료 |
| Python CLI 진입점 | argparse 실행 도구 11개의 --help/import 정상 |

영상 시험은 검정/비대상색, 타워 1개/2개, ROI 좌표·contour 변환, 경계 ROI, 출력 마스크 구성을
확인한다. 단일 파일 추적기의 좁은 녹색 임계값은 범용 검출기 기본값과 다르므로 해당 범위의
합성색을 사용한다. 로컬 PC 영상 실행은 라즈 카메라 성능/GUI 검증이 아니다.
보조 영상 변환·UI·CAD 스크립트는 역할/구문을 검토했지만 모든 파일의 모든 실행 경로를
실물 검증하지 않았다. 기존 Cppcheck 기록을 이번 실행 결과로 재사용하지 않는다.

중요한 미구현 연결: 현재 `scripts/pi_green_tracker.py`와 `raspberry_pi_green_tracker_single.py`는
화면/텍스트/JSON 출력이며, ESP32의 14바이트 UART 송신을 하지 않는다. UART1 파서는 구현되어
있지만 카메라 → Pi 송신 → ESP32 종단간 동작을 완료했다고 볼 수 없다.

재현 명령: 생산 `tests/run_host_tests.ps1`, 벤치 동일 명령의 `-Bench`, 저장소 루트에서
`.venv/Scripts/python.exe -m unittest discover -s tests -v`.

## 1. 이번 작업의 기준

### 후속 센서 최적화 (2026-10-05)

AS7341은 이전 두 뱅크 방식 대신 F2/F3/F5/F6/F7/Clear 단일 묶음 연속 측정으로 변경했다.
기본 노출 5000us 요청(4998.44us 실제 설정), X16, 센서별 LED 20mA이며 실측 전 시작값이다.
완료 이벤트 AINT(APERS=0, SP_IEN)와 최소 수광 간격으로 새 샘플을 구분한다.
ASTATUS부터 버스트 읽기로 래치/포화를 검사한다. 초기 SMUX 이후 수광을 끄지 않는다.
모의 시험에 완료 이벤트 write-one-to-clear, 연속 측정, 단일 묶음 채널 매핑,
동일 시각 중복 읽기, 포화 해제 후 유효 측정을 추가했다. 검증 결과는 아래 기존 기록보다
이 후속 변경의 결과를 우선한다. 광학 성능/실제 최대 지연은 미검증이며 상세 조건은 README에 있다.

후속 검증: AS7341 12그룹/4,981회, TCS34725 12그룹/4,542회 PC 검사 통과.
생산/센서 전용 × AS7341/TCS34725 네 PlatformIO 환경 모두 빌드 성공.

- V1 핀 배치를 유지한다. PCBV2 핀 배치는 적용하지 않는다.
- 바닥 센서는 컬러 센서 네 개뿐이다. IR, IMU, 전류, 엔코더, 배터리 ADC를 추가하지 않는다.
- 센서 1/2/3/4는 전방 왼쪽/전방 오른쪽/후방 왼쪽/후방 오른쪽이다.
  모터 1은 왼쪽, 모터 2는 오른쪽이다.
- AS7341 또는 TCS34725 한 종류를 빌드 시 선택한다. 두 종류를 동시에 꽂는 구성은 아니다.
- 오류 복구 엔진을 만들지 않는다. 채널 오류는 한 번 기록하고 해당 채널을 제외한다.
- SW1 안전 정지와 모터 명령 만료는 단순 오류 출력보다 우선하는 필수 안전 기능이다.
- 공격 전략의 세부 최적화는 하지 않는다. 기존 시간 기반 공격을 유지하고 구조적 오류를 수정한다.

## 2. 요구사항과 구현 대응

| 요구사항 | 현재 구현 | 담당 파일 |
|---|---|---|
| V1 GPIO 번호로 직접 사용 | 기존 V1 핀 그대로 | `include/pins.hpp` |
| 센서 종류 한 줄 선택 | `COLOR_SENSOR_MODEL` | `include/sensors/sensor_config.hpp` |
| 수광 시간·게인 쉽게 조정 | AS7341 EXPOSURE_US/GAIN/LED, TCS34725 INTEGRATION/GAIN | 같은 설정 파일 |
| 네 모서리의 같은 주소 센서 | TCA 기본 0x70, 채널 0/1/2/3 단일 선택 | `src/sensors/color_sensor_manager.cpp` |
| 센서 부팅 실패에도 진행 | 실패 채널만 Unknown, 부팅은 계속 | `src/sensors/sensor_manager.cpp` |
| 같은 색 3회 이상 | 실제 새 측정 sequence 세 번, 루프 반복은 세지 않음 | 같은 파일 |
| 비율 기반 색 판별 | 색 채널/Clear, 교정 시 세 높이 기준과 밝기를 함께 비교 | `src/sensors/floor_color_classifier.cpp` |
| 교정 없이 구동 | 설정 파일의 임시 하드코딩 임계값 사용 | 같은 파일 |
| 교정 코드는 별도 | UART 안내, 48단계, 각 3초 측정, NVS 저장 | `src/sensors/color_calibration.cpp` |
| 교정은 시작 전만 | 교정 중 모터 금지; SW2로 중단한 제스처는 출발에 사용하지 않음 | `src/main.cpp`, `src/system/system_manager.cpp` |
| UART0 로그 57600 | 변경 시 로그, 제한된 큐·출력량 | `src/system/event_logger.cpp` |
| UART1 라즈 115200, 50Hz 통보 | 14바이트 고정, CRC 없음, sequence·범위 검사 | `src/communication/raspberry_link.cpp` |
| 라즈 미연결/재부팅 정상 시나리오 | 시스템 고장으로 만들지 않고 탐색으로 전환 | `src/control/robot_fsm.cpp` |
| SW1 눌림 즉시 영구 정지 | ISR EN 차단, 브레이크 유지, 이후 ESTOP만 3초마다 | `src/interrupts/button_interrupts.cpp` |
| SW2 놓을 때 한 번 시작 | 눌림/해제 각각 40ms 디바운스; 부팅부터 눌린 버튼 해제는 무시 | 같은 파일 |
| 공용 모터 API·상태 조회 | tank/arcade/전후진/회전/정지/제한/status | `src/motor/motor_controller.cpp` |
| PWM 범용 설정 | 20kHz, 8비트; API는 -1000~1000; 기본 출력 상한 650 | `include/motor/motor_config.hpp` |
| 명령이 끊기면 정지 | 공용 API 기본 100ms, FSM 80ms, 별도 5ms 만료 감시 | 모터 제어 및 `include/control/control_config.hpp` |
| LED 우선순위·공용 호출 | 내장48/외부13, 요청 우선순위, 같은 우선순위 최신 요청, TTL | `src/system/status_led.cpp` |
| 모터를 건드리지 않는 센서 시험 | 별도 환경, 100ms마다 센서/버튼 출력 | `src/sensor_serial_test.cpp` |

## 3. 실제 실행 흐름

```text
전원/리셋
  → 모터 핀 안전 LOW → UART 로그 열기 → PWM 초기화
  → 버튼 ISR → LED → 컬러 센서/NVS → 라즈 UART → 안전관리자
  → 시작 대기 (모터 브레이크)
       ├─ CAL START → 자세 안내 → READY → 카운트다운 3초 → 측정 3초
       │              → ACCEPT/RETRY/BACK → 48단계 완료 → CAL SAVE
       └─ SW2 정상 눌림·해제 → 운전 허용

운전 루프
  안전/버튼/모터 만료 확인
    → 라즈 패킷 읽기 → 컬러 센서의 짧은 I2C 단계 → 안전 다시 확인
    → FSM 판단 → 좌우 명령 변환 → 출력 제한/PWM 적용
    → LED → 제한된 이벤트 로그 → 1ms 양보

FSM 기본 흐름
  탐색 → 서로 다른 목표 프레임 2회 확인 → 정렬/접근
       → 가까운 중앙 목표 → 돌진 220ms → 브레이크 90ms
       → 스포크 삽입 전진 350ms → 밀기
       → 목표 상실 시 마지막 새 목표 시각 기준 최대 500ms 밀기
       → 후진 260ms → 탐색

우선 처리
  SW1 → 모든 일반 실행 종료, 재부팅 필요
  신뢰 가능한 위험색 → 공격 어느 단계에서든 위험구역 회피
```

센서·FSM·통신은 읽기 쉬운 메인 루프에 그대로 있다.
모터 명령 만료만 작은 FreeRTOS 태스크에서 별도로 감시한다.
이는 메인에서 센서/I2C 처리 중이어도 만료된 구동을 정지시키기 위한 것이다.
감시 주기는 5ms이며 80/100ms에 정확히 일치하는 하드 실시간 정지를 보증하지는 않는다.

## 4. 현실적인 조합의 처리 정책

| 상황 | 처리 |
|---|---|
| 전원 인가, SW2 미조작 | 센서/통신은 읽지만 주행하지 않음 |
| 부팅부터 SW2 눌림 | 첫 해제로 출발하지 않음; 다시 눌렀다 놓아야 함 |
| 라즈가 아예 없음 | SW2 시작 후 탐색 가능 |
| 라즈가 재부팅·중단 | 짧은 목표 상실 처리 후 탐색; 시스템 시작 상태는 유지 |
| 라즈가 같은 sequence만 재전송 | 통신 생존과 영상 신선도를 구분; 영상은 120ms 뒤 오래된 것으로 판단 |
| 끊긴 라즈가 새 정상 패킷 전송 | 다음 정상 입력으로 사용; 재접속/재부팅 명령을 보내지는 않음 |
| 컬러 센서 하나/전체 초기화 실패 | 채널 오류와 Unknown; 부팅/시작은 계속 |
| 사용 중 센서 I2C/수광 타임아웃 | 해당 채널은 재부팅 전까지 제외; 자동 초기화·재시도 없음 |
| 무수광/포화 값 | 해당 측정만 무효; 동일한 오류는 반복 기록하지 않음 |
| 색이 바뀌었거나 무효 값 입력 | 이전 reliable 판정을 바로 취소; 새로운 같은 색 세 번 필요 |
| 교정 데이터 없음/형식·설정 불일치 | 임시 임계값 사용; 자동 교정하지 않음 |
| 교정 중 SW2 조작 | 교정 중단, 모터 계속 정지; 별도의 새 눌림·해제 필요 |
| 교정 NVS 저장/삭제 실패 | 오류 출력; 수동 명령만 허용, 기존 RAM 교정 데이터 보존 |
| 모터/애플리케이션 집계 고장 | 즉시 정지·운전 요청 폐기; 상태가 정상으로 보고되어도 자동 출발하지 않음 |
| 모터 명령 만료 | 브레이크, 다음 새 정상 명령이 없으면 계속 정지 |
| SW1 입력 | 구동 영구 금지; 스위치 해제/소프트웨어 해제 API로 복구 불가 |

라즈의 새 입력을 다시 사용하는 것과 범위 오류 이후 다음 정상 측정을 읽는 것은
일반 입력 처리다. 센서 리셋, 보드 재부팅, 재접속 루프 등의 자동 복구는 구현하지 않았다.

## 5. 발견해 수정한 주요 문제

1. 센서 라이브러리의 수광 대기/SMUX 대기로 제어 루프가 길게 정지할 수 있었다.
   짧은 Wire 레지스터 단계와 유한 타임아웃으로 바꾸었다. 수광 시간만큼 delay하지 않는다.
2. 목표가 오른쪽일 때 전진 조향 부호가 반대였다. 오른쪽 조향은 왼쪽 모터가 더 빠르도록 통일했다.
3. 브레이크 전환 시 이전 PWM 상태에서 EN부터 올리는 순간 구동 위험이 있었다.
   EN 차단 → 브레이크 PWM → EN 설정 순서로 바꾸었다.
4. ESTOP 정지 루프의 반복 EN LOW가 브레이크를 취소할 수 있었다.
   ISR의 즉시 차단 이후에는 선택한 전기적 브레이크 조합을 유지한다.
5. ESTOP 브레이크 중 공용 드라이버 호출이 PWM을 먼저 바꿀 수 있었다.
   구동 금지 확인을 출력 전/EN 직전에 적용했다. 실제 SW1 래치는 해제할 수 없다.
6. 모터 만료 감시가 메인 루프에만 의존했다. 작은 별도 만료 감시를 추가했다.
   시간 카운터 순환 시 기한 0도 실제 기한으로 처리한다.
7. 안전 고장 보고 후 motorAllowed가 한 루프 동안 이전 값일 수 있었다.
   보고 시점에 안전 상태를 갱신하고 기존 출발 요청을 폐기한다.
8. 버튼 해제의 짧은 재채터링이 디바운스 시간을 단축할 수 있었다.
   새 에지가 들어오면 안정화 시간을 다시 센다.
9. UART 중간 바이트 유실 시 다음 헤더를 버리거나 라즈 재부팅 sequence를 거부할 수 있었다.
   후보 헤더 꼬리를 보존하고 끊김 이후 첫 정상 패킷은 새 sequence 기준으로 받는다.
10. 목표 유효 시간을 현재 루프 시각으로 계속 늘릴 수 있었다.
    실제 새 영상 시각을 기준으로 목표 상실 시간을 계산한다.
11. 캘리브레이션 긴 입력 뒤 남은 문자열이 명령이 될 수 있었다.
    손상/너무 긴 입력은 줄 끝까지 버린다. 저장 길이·유한값·설정 호환도 검사한다.
12. 캘리브레이션 구조체 초기화에 약 4.6KB 스택 임시값이 생겼다.
    작은 참조 단위로 초기화해 해당 컴파일 경고를 없앴다.
13. 빨강/노랑 임시 판정 범위가 겹쳐 빨강이 노랑으로 먼저 판정될 수 있었다.
    우세 빨강을 먼저 검사하고 모든 색의 예제를 시험했다.
14. I2C 전송 후 새 샘플 시각이 이전 루프 시각보다 늦어 unsigned 나이 계산이 잘못될 수 있었다.
    전송 후의 시각으로 샘플 신선도를 검사한다.
15. AS7341 ADC 값을 데이터 래치 없이 읽을 수 있었다.
    ASTATUS부터 연속 읽고 아날로그/디지털 포화 상태를 함께 처리한다.
16. 로그 송신 공간의 고정 최소치만 확인해서 긴 로그가 UART 쓰기를 기다릴 수 있었다.
    실제 한 줄 전체 길이를 확인한 뒤 쓰고, 공간이 없으면 다음 루프로 미룬다.
17. LED TTL이 millis 순환 시 0이면 영구 요청으로 바뀔 수 있었다.
    만료 여부와 만료 시각을 분리했다. 실제 FSM 상태가 바뀔 때만 LED 요청한다.

## 6. 재현 가능한 하드웨어 없는 검증

작업 폴더의 PowerShell에서:

```powershell
cd D:\C_ROBOT\ESP_MAIN
.\tests\run_host_tests.ps1
```

실제 생산 소스와 `setup()/loop()`를 PC용 가짜 GPIO/UART/I2C/NVS에 연결한다.
FSM/안전/판정 알고리즘을 별도의 가짜 구현으로 바꾸지 않는다.
AS7341과 TCS34725를 각각 컴파일하고 12개 시험 그룹을 실행한다.
네이티브 g++가 필요하며 PATH 또는 PlatformIO의 toolchain-gccmingw32를 사용한다.
시험 파일은 생산 빌드에 들어가지 않는다. 출력 실행 파일은 `.pio/host-tests`에 둔다.

검증 그룹:

- 모터 제한·조향·100ms 만료·시간 순환
- 버튼 채터링·부팅 눌림·출력 변경 중 SW1 인터럽트
- 시작·고장 즉시 금지·수동 재시작·교정 금지
- UART 중복/손상/바이트 유실/라즈 재부팅/sequence 순환/무작위 바이트 5만 개
- FSM 공격 시각 경계·공격 각 단계의 위험색 우선 처리·네 모서리 회피·목표 상실
- 센서 정상/미연결/포화/변환 정지/SMUX 정지/자동 재초기화 금지
- 새 색 측정 세 번과 색 변경 시 기존 판정 취소
- 실제 48단계 교정, 서로 다른 자세 밝기, RETRY/BACK, 저장·삭제 실패, NVS 손상
- 로그 송신 공간 부족과 LED 우선순위/만료/시간 순환
- 실제 메인 루프의 시작·교정 중단·라즈 없는 탐색
- I2C 거래마다 시간이 흐르는 조건, 전체 센서 누락 부팅, 모터 초기화 실패, 부팅 SW1

공격 상태가 변하는 간단한 출력 데모:

```powershell
.\tests\run_host_tests.ps1 -Demo
```

이는 가상 시각과 가상 입력을 이용한 흐름 시연이다. 실제 차량/영상/물리 시뮬레이터는 아니다.

ESP32용 네 가지 빌드:

```powershell
pio run -e yd_esp32_s3 -e yd_esp32_s3_tcs34725 -e sensor_serial_test -e sensor_serial_test_tcs34725
```

검토 중에는 기존 산출물 잠금을 피하려고 `PLATFORMIO_BUILD_DIR=.pio\build_review`를 사용했다.
센서 단일 묶음 최적화 이전의 실행 기록 (최신 결과는 문서 상단):

| 검증 | 결과 |
|---|---|
| AS7341 PC 시험 | 11개 그룹, assert 검사 4,845회 통과 |
| TCS34725 PC 시험 | 11개 그룹, assert 검사 4,542회 통과 |
| ESP32 네 환경 | 모두 빌드 성공, 프로젝트 소스 경고 없음 |
| Cppcheck warning/performance/portability | 소스 19개 파일 통과 |
| 생산 AS7341 메모리 | RAM 36,188 bytes / Flash 368,853 bytes |
| 생산 TCS34725 메모리 | RAM 36,188 bytes / Flash 368,381 bytes |

assert 횟수에는 반복 측정 시 시간 비블로킹 확인 등이 포함된다.
9천여 개의 서로 다른 시나리오라는 뜻은 아니다.
최종 수치와 통과 결과는 테스트 출력 및 빌드 출력이 원본이다.

## 7. 실물에서 반드시 확인할 부분

코드 시험만으로 아래 항목을 확정할 수 없다.

1. 실제 보드의 플래시 용량과 업로드 설정. 현재 8MB DevKitC 설정이며 PSRAM은 사용하지 않는다.
2. BTS7960 실제 EN/PWM 배선과 브레이크 효과. 현재 BothPwmLowEnableHigh이며 실측 검증 전이다.
   전원 리셋 중의 하이임피던스와 드라이버 풀다운도 소프트웨어만으로 보장할 수 없다.
3. 좌/우 모터 정방향. 방향 반대이면 motor_config.hpp의 LEFT/RIGHT_MOTOR_INVERTED를 바꾼다.
4. 센서 모듈의 보조 조명과 실제 TCA 채널 순서, 배선 길이·I2C 풀업·버스 품질.
5. 실제 경기장 색과 높이별 판정. 임시 임계값은 미교정 출발용 초기값이지 검증된 경기용 값이 아니다.
   V1에는 IMU/거리센서가 없으므로 상대 로봇 표면/공중/검정 바닥을 항상 구분할 수는 없다.
6. 실제 수광 주기와 3회 확인 지연. 100Hz는 목표이며 현재 달성했다고 주장하지 않는다.
   현재 AS7341은 전체 스펙트럼 대신 단일 묶음 약 5ms 연속 수광이다.
   내부 보정/I2C/스케줄링/누락된 샘플/단차 경계의 혼합색 때문에 20ms/10mm를 최대값으로 보장하지 않는다.
   TCS34725를 614ms 수광으로 바꾸면 3초당 최소 5샘플 교정 조건을 못 채울 수 있어 측정 시간도 조정한다.
7. ESP32의 실제 ISR/FreeRTOS 동시 실행과 만료 지연. PC 테스트는 결정적인 인터럽트 타이밍을 모델링할 뿐이다.
8. 라즈 실제 송신과 종단간 UART. CRC가 없으므로 형식상 정상인 비트 손상까지 모두 검출하지는 못한다.
9. 급정거·스포크 기동과 출력 65%의 실제 기체 안정성. 시간 기반 제어일 뿐 접촉/삽입 성공을 측정하지 않는다.

빠른 첫 시연 순서:

1. 모터 전원을 분리하고 센서 전용 테스트 환경으로 UART0 115200에서 네 센서 순서를 확인한다.
2. 출력 상한을 먼저 낮추고 바퀴를 띄워 생산 환경으로 업로드한다. UART0는 57600이다.
3. 전원 직후 무구동 → SW2 눌림·해제 → 좌우 방향 → SW1 즉시 차단/브레이크 유지/ESTOP만 출력 확인.
4. SW1을 놓아도 출발하지 않고 재부팅해야 하는지 확인한다.
5. 라즈 없이 탐색 → 라즈 정상 송신 → 분리/재부팅 시 탐색 전환을 확인한다.
6. 바닥에서 돌진하기 전에 실제 색/높이 교정과 위험색 회피부터 낮은 출력으로 확인한다.

## 8. 레지스터 확인 근거

AS7341의 ADC 래치, 포화, 초기화 대기, 수광 시간은 제조사
[AS7341 DS000504](https://look.ams-osram.com/m/24266a3e584de4db/original/AS7341-DS000504.pdf)의
32~33, 47, 49쪽을 대조했다. SMUX 연결 값은
[Adafruit AS7341 라이브러리](https://github.com/adafruit/Adafruit_AS7341/blob/master/Adafruit_AS7341.cpp)의
F1~F4/F5~F8 연결 정의와 대조했다. 자료 대조는 실제 센서 실험을 대신하지 않는다.

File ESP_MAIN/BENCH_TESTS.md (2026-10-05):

# V1 실물 시험 펌웨어

생산 공격 FSM과 별도인 테스트 코드다. V1 핀·기존 센서 설정·SW1 영구 비상정지·모터 명령
만료 감시는 그대로 사용한다. 돌진/급정거/스포크 기동은 실행하지 않는다.

## 업로드 및 연결

`D:\C_ROBOT\ESP_MAIN`에서:

```powershell
pio run -e robot_bench -t upload
pio device monitor -e robot_bench -b 57600
```

TCS34725 기체는 두 명령의 환경 이름을 `robot_bench_tcs34725`로 바꾼다.
명령은 UART0(COM/SiK 공용), 57600bps, 대문자, 줄바꿈으로 전송한다.
PlatformIO 모니터는 기본적으로 로컬 입력이 안 보일 수 있다. Enter로 전송하거나
터미널에서 줄바꿈(LF/CRLF)을 설정한다. UART1은 기존 라즈 115200bps/14바이트 패킷용이다.
UART0의 COM/SiK 수신 출력 둘을 동시에 구동하지 않는다.

## 모드와 사용 순서

부팅 시 `STOP`으로 시작한다. `MODE ...`는 항상 먼저 정지하고 기존 수동 명령을 폐기한다.
주행 모드는 선택한 뒤 **SW2를 눌렀다 놓아야** 시작한다. UART 명령으로 시작 안전을 우회하지 않는다.
`STOP`으로 언제든 소프트웨어 정지한다. 다시 움직이려면 SW2를 새로 눌렀다 놓는다.
SW1은 누르는 즉시 영구 비상정지이며 해제 후에도 재부팅해야 한다.

| 명령 | 시험 내용 |
|---|---|
| `MODE MOTOR` | 왼쪽 정방향 3초 → 0.5초 정지 → 왼쪽 역방향 3초 → 정지 → 오른쪽 정/역 각각 3초. 한 번만 실행 후 정지 |
| `MODE MANUAL` | SW2 시작 후 `DRIVE <왼쪽> <오른쪽>`으로 독립 제어 |
| `MODE DATA` | 움직이지 않고 센서·라즈·모터 상태 로그 자동 출력. SW2 불필요 |
| `MODE ALIGN` | 타워 중심 X가 960±100 밖이면 제자리 회전, 중앙에 들어오면 정지. 전진하지 않음 |
| `MODE FOLLOW` | 중앙 타워를 추적하며 전진. 크게 벗어나면 회전만. 박스 높이 420 이상 또는 중앙 근처의 잘린 박스에서는 정지 |
| `MODE AVOID` | 추적 + 빨강/노랑/파랑 바닥 회피. 검정만 정상 바닥으로 취급 |
| `MODE STOP` | 모드 선택 없이 움직이지 않음 |

`ALIGN/FOLLOW`는 **바닥을 검사하지 않는다.** 안전한 넓은 곳에서 시험한다.
`FOLLOW/AVOID`의 박스 높이는 거리계가 아니라 임시 접근 정지 기준이다.
타워 박스가 커도 크게 옆에 있으면 먼저 회전 정렬할 수 있다. 공격/밀기/목표 수색은 하지 않는다.
타워가 없거나 UART/프레임/카메라/처리 상태가 유효하지 않으면 추적은 정지한다.
AVOID에서 이미 진행 중인 짧은 바닥 회피는 타워 정보보다 우선하며 계속할 수 있다.

`AVOID`는 네 바닥센서가 모두 신뢰 가능하고 최신이어야 움직인다.
하나라도 오류/Unknown/포화/오래된 판정이면 정지한다. 색 변경 후 3회 확정 중에도 잠시 멈출 수 있다.
전방 위험은 후진, 후방 위험은 전진 250ms 후 위험 방향 반대쪽으로 회전 250ms 한다.
전후방에 동시에 위험색이 있거나 회피 진행 방향에 위험이 생기면 정지한다.
현재 위험 구역을 물리적으로 벗어났다고 보장하는 로직은 아니며 추가 기구/거리센서가 없다.

## UART 수동 제어

```text
MODE MANUAL
# 여기서 SW2를 눌렀다 놓는다. 이 주석 줄은 전송하지 않는다.
DRIVE 100 100
DRIVE -100 100
STOP
```

숫자는 퍼센트가 아니라 **천분율**이다. `100`은 10%, 허용 범위는 `-200..200`(±20%).
`DRIVE`는 유지 스위치처럼 **250ms 안에 반복 전송**해야 한다. 새 명령이 없으면 정지한다.
단일 명령을 계속 래치하지 않는다. 안전이 풀리기 전에 입력한 명령도 저장하지 않는다.
잘못된 명령/범위 초과/지나치게 긴 줄/250ms 넘게 끊긴 미완성 줄은 정지 처리한다.
`HELP`도 안전하게 정지한 뒤 도움말을 출력한다. 입력이 끊긴 줄은 다음 줄바꿈까지 버린다.

## 데이터 출력

`LOG ON` / `LOG OFF`로 어느 모드에서든 켜고 끈다. `STATUS`는 로그 출력을 켜고 다음 프레임을 요청한다.
`EV,...`는 기존 이벤트 로그, `D,...`는 로봇 상태, `S,...`는 센서별 데이터다.
100ms 주기로 출력 시도하되 UART 공간이 부족하면 기다리지 않고 일부 프레임을 생략한다.
출력 주기는 센서 수광 주기가 아니며, 각 행은 읽는 시점이 조금 다를 수 있다.

```text
D,시간ms,모드,모터허용,좌출력,우출력,라즈연결,프레임최신,타워유효,X,박스높이,위험센서비트
S,시간ms,센서번호,sequence,원시값유효,판정색,색확정,Clear,값1,값2,값3,값4,값5,센서오류번호
```

AS7341의 값1..5는 F2/F3/F5/F6/F7이다. TCS34725는 R/G/B/Clear/Clear이며 마지막 Clear는
고정 출력 형식을 위한 중복 칸이다. 센서 순서는 전방 왼쪽/전방 오른쪽/후방 왼쪽/후방 오른쪽.
위험센서 비트 0..3은 같은 순서다. 출력은 분류 실패/포화 때도 원시값을 보여준다.

## 조정과 검증

- 시험 출력·수동 명령 유효시간·회전/추적/회피 시간: `include/bench/bench_config.hpp`
- 바닥 수광·게인·LED·임계값: `include/sensors/sensor_config.hpp`
- 타워 기준은 1920×1080 좌표이며 라즈 송신 규격은 기존 펌웨어와 같다.
- 바닥은 구조물 없이 3/10/20mm 간격, 자체 LED, 10mm 단차 조건이다. 근접 포화/먼 거리 검정 오인/
  경계 혼합은 실측해야 한다. 회피 모드라고 가장자리에서 안전하다고 보장할 수 없다.
- 처음에는 바퀴를 띄우고 MOTOR/MANUAL부터 확인한다. 12% 출력에서도 실제 속도/토크는 기체에 따라 다르다.
- 실제 구동 모터·UART·카메라·바닥에 대한 실물 검증은 아직 하지 않았다.

```powershell
.\tests\run_host_tests.ps1 -Bench
.\tests\run_host_tests.ps1
pio run -e robot_bench -e robot_bench_tcs34725
```

테스트 코드는 `src/bench_main.cpp`(입출력/안전 연결), `src/bench/bench_controller.cpp`(모드별 주행)로 나뉜다.
테스트 환경은 기존 `src/main.cpp`를 빌드하지 않는다. 생산 환경은 테스트 메인과 컨트롤러를 빌드하지 않는다.

2026-10-05 최신 PC 검증: AS7341/TCS34725 각각 67개 검사 통과. 모터 시간 순서, 수동 명령 만료와
millis 순환, 정렬/추적/회피, UART 패킷 수신과 끊김, 모드 변경 정지, 잘못된/긴/끊긴 명령,
UART 출력 공간 부족, SW1 영구 정지를 확인했다. 생산 펌웨어의 기존 12개 시험 그룹도 통과했다.
모드 변경 직전에 누르기 시작한 SW2의 해제는 새 모드 출발에 사용하지 않는다.
잘못된 공개 모드 값은 STOP으로 처리하고, 회피 회전 중에도 현재 위험 방향을 다시 반영한다.
생산/센서 전용/벤치 × 두 센서 구성의 여섯 PlatformIO 환경 빌드 성공. 실물 시험은 별도다.

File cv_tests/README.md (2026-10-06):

# 컬러타워 필터 비교 테스트

기존 라즈 추적기와 분리된 새 실험입니다. 기존 CV/ESP 코드와 UART 통신을 바꾸지 않습니다.
모든 방식은 같은 영상을 입력받고, 현재 프레임의 가장 큰 색 영역 하나를 선택합니다.
이전 박스를 유지하거나 예측하는 기능은 없습니다. 따라서 검출이 없는 프레임을 숨기지 않습니다.

## 비교 방식

| 별도 실행 파일 | 계산하는 필터 | 최종 판정 |
|---|---|---|
| `test_01_four_vote.py` | BGR, ExG, HSV, Lab | 4개 중 3개 이상 |
| `test_02_no_exg.py` | BGR, HSV, Lab | 3개 중 2개 이상 |
| `test_03_no_lab.py` | BGR, ExG, HSV | 3개 중 2개 이상 |
| `test_04_no_bgr.py` | ExG, HSV, Lab | 3개 중 2개 이상 |
| `test_05_hsv.py` | HSV | HSV 통과 |
| `test_06_normalized.py` | 정규화 RGB 초록 비율 | 비율 조건 통과 |
| `test_07_hsv_normalized.py` | HSV, 정규화 RGB | 둘 다 통과 |
| `test_08_hsv_cascade.py` | 절반 해상도 HSV, 원본 ROI HSV | 축소 후보를 원본에서 재검사 |

각 테스트는 별도 파일로 직접 실행됩니다. 공통 판정·영상 저장 코드만 `comparison_engine.py`에 둬서
버전별로 최소 면적이나 박스 계산이 달라지는 문제를 막았습니다. 빠진 필터는 실제로 계산하지 않습니다.

3/4와 2/3은 판정 규칙이 다릅니다. 따라서 이 비교는 방식별 정확도/속도 비교이지,
정확도가 완전히 고정된 순수 필터 제거 실험은 아닙니다.
특히 BGR와 ExG는 같은 채널 차이를 이용하므로 독립적인 두 표가 아닙니다.

## 공통 설정

`comparison_engine.py` 상단에서 수정합니다.

- HSV: H 35~90, S 60~255, V 35~255. OpenCV H 범위는 0~179입니다.
- Lab: L 15~255, a 0~125, b 135~255. OpenCV 8비트 인코딩 기준입니다.
- BGR: G≥40, G−R≥20, G−B≥20.
- ExG: 2G−R−B≥45, G≥35 및 위의 두 채널 차이 조건.
- 정규화: G/(R+G+B)≥0.42, (G−R)/(합)≥0.08, (G−B)/(합)≥0.08, G≥35.
  나눗셈 대신 동등한 선형 부등식을 OpenCV 변환으로 계산합니다.
- 최종 마스크에만 3×3 닫힘 처리. 작은 먼 표적이 사라질 수 있는 열림/침식은 하지 않습니다.
- 최소 윤곽 면적 8픽셀. 가장 큰 외곽 윤곽의 모멘트 중심과 축 정렬 박스를 반환합니다.
- 원본 1080×1920에서 검사. 08번만 탐색을 540×960에서 하고 후보 주변을 원본으로 확인합니다.
- 08번은 면적 1 이상인 축소 윤곽을 모두 확인하고, 원본 기준 12픽셀 여유를 줍니다.
  후보가 많고 영역이 겹치면 반복 검사 비용이 증가할 수 있습니다. 작은/흐린 타워가 축소에서
  없어지면 복구할 수 없다는 한계도 있습니다.

기존 `config/color_detector_last.json`의 좁은 임계값과 면적 300은 가져오지 않았습니다.
먼 타워를 놓치지 않는 접근을 비교하기 위한 넓은 공통 범위입니다.

## 실행

프로젝트 루트 `D:\C_ROBOT`에서 실행합니다. Python 환경은 이미 있는 `.venv`를 사용합니다.
필요 패키지는 OpenCV와 NumPy뿐입니다.

```powershell
# 한 방식만 실행하고 영상 저장
.\.venv\Scripts\python.exe cv_tests\test_05_hsv.py

# 화면도 표시; Q 또는 ESC 종료
.\.venv\Scripts\python.exe cv_tests\test_02_no_exg.py --show

# 다른 영상과 별도 결과 경로
.\.venv\Scripts\python.exe cv_tests\test_01_four_vote.py "D:\videos\input.mp4" --output "D:\videos\four.mp4"

# 회귀 테스트
.\.venv\Scripts\python.exe cv_tests\test_comparison.py
.\.venv\Scripts\python.exe cv_tests\test_pipeline.py

# 전체 8방식 비교. 재실행은 새 출력 폴더 사용
.\.venv\Scripts\python.exe cv_tests\run_comparison.py --output outputs\cv_comparison_new

# 원본만 담은 독립 정답 검토용 표본 이미지
.\.venv\Scripts\python.exe cv_tests\run_comparison.py --references --output outputs\cv_comparison_new

# 평가/스트레스 테스트/보고서 생성 (기본 휴대폰 영상용 주석 기준)
.\.venv\Scripts\python.exe cv_tests\analyze_comparison.py --output outputs\cv_comparison_new

# 저장한 박스를 같은 시점에 8개 나란히 비교하는 종합 영상
.\.venv\Scripts\python.exe cv_tests\build_overview.py --output outputs\cv_comparison_new

# 저장 영상의 모든 프레임을 다시 디코딩해서 확인
.\.venv\Scripts\python.exe cv_tests\verify_videos.py --output outputs\cv_comparison_new
```

개별 실행은 출력 파일을 덮어쓸 수 있으므로 보존할 결과에는 다른 `--output`을 사용합니다.
전체 비교 실행은 `metrics.csv`가 있는 폴더에 다시 저장하지 않도록 보호합니다.
중도 종료한 비교를 완료 결과로 사용하지 않습니다. `summary.json`이 생성되고
각 영상의 프레임 수와 처음/마지막 디코딩 검사가 성공한 결과만 완료입니다.

## 영상 구성과 시간 해석

각 방식은 810×960, 3열×2행 MP4로 저장합니다. 원본 FPS와 전체 프레임 수를 유지합니다.

```text
원본 + 박스/중심 | 개별 마스크 1 | 개별 마스크 2
개별 마스크 3   | 개별 마스크 4 | 최종 마스크 + 박스
```

사용하지 않는 칸에는 `UNUSED - NOT COMPUTED`가 표시됩니다. 개별 마스크는 닫힘 처리 전,
최종 마스크는 투표/교집합과 닫힘 처리 후입니다. 축소된 마스크 화면은 검토용이며 판정은
원본 마스크에서 수행합니다. 원본의 소리는 저장하지 않습니다.

`detect_ms`에는 색 변환, 마스크 생성/합성, 닫힘 처리, 윤곽 추출, 최대 표적 선택이 포함됩니다.
디코딩·화면 합성·인코딩은 제외합니다. `render_encode_ms`는 영상 합성/저장 호출 시간입니다.
비교에서는 각 방법을 독립 계산하고 매 프레임 실행 순서를 회전합니다.
OpenCV 1스레드로 고정하고 첫 30프레임을 속도 통계에서 제외합니다.
단독 실행은 컴퓨터의 OpenCV 기본 스레드 설정을 사용하므로 시간이 다를 수 있습니다.

`1000/연산시간`은 CV-only 처리 가능 FPS이지 카메라 포함 실제 FPS가 아닙니다.
영상 재생은 원본 약 29.979fps이고, 저장 영상을 30fps로 본다고 검출기가 30fps라는 의미도 아닙니다.
50Hz 목표는 검출기 p95/p99와 20ms 초과 비율로 비교합니다. 라즈5에서는 다시 측정해야 합니다.

## 자체 평가 기준

1. 전체 4,280프레임: 시간, 검출 유무, 박스, 중심, 면적을 기록합니다.
2. 수작업 표본 48개: 순차 디코딩한 원본만 보고 타워 위치를 정합니다. 45개는 타워가 보이고 3개는 화면 밖입니다.
3. 정답 박스 15% 여유 범위 안에 중심이 있고 IoU≥0.25면 정답입니다.
   표본 박스는 축소 이미지의 육안 추정이므로 픽셀 단위 정밀 정답이 아닙니다.
4. 정답/다른 물체 선택/검출 없음/타워 없는 장면의 오검출을 구분합니다.
5. 45개 타워 표본에서 타워 주변을 회색으로 지워 초록 배경을 잡는 성향을 검사합니다.
   실제 촬영한 타워 부재 영상이 아니므로 합성 오검출 진단으로 따로 집계합니다.
6. 표본 12개에 밝기 0.5배/1.4배, 노이즈 σ12, 5×5 Gaussian 흐림을 각각 적용한 48개 스트레스 검사를 합니다.
7. 현재의 재현율 우선 요청에 따라 표본 정답 수 → 스트레스 정답 수 → p95 시간 순으로 정렬합니다.
   충분한 실제 음성 영상이 없어 이 순위를 대회용 오검출 안전성 순위로 해석하면 안 됩니다.
8. 별도로 p99≤20ms인 방식만 남겨 50Hz 연산 예산 안의 후보를 정합니다.
   이 PC의 검출만 측정한 조건이므로 카메라·UART·라즈 처리까지 보장하지 않습니다.

전체 프레임을 사람이 모두 정답 표시하지 않았으므로 **한 번도 놓치지 않았다는 보장은 할 수 없습니다.**
검출률이 높아도 배경의 초록 매트/식물을 잡으면 실패입니다. 색 필터만으로 같은 색의 다른 물체와
원통을 완전히 구분할 수 없습니다. 박스 흔들림은 카메라 자체 기동과 섞이므로 정확도 점수에
무조건 넣지 않습니다. 다음 단계에서 형태/시간적 일관성을 별도로 비교할 수 있습니다.

휴대폰 영상에서 `CAP_PROP_POS_FRAMES`로 이동해 읽은 프레임과 순차 디코딩 프레임이
다른 경우를 실제로 발견했습니다. 따라서 평가용 표본/스트레스/후보 진단은 `video_frames.py`로
처음부터 순서대로 읽어 같은 번호의 프레임을 사용합니다. seek 기반 중간 점수는 최종 결과가 아닙니다.
영상에 표시한 초 단위 시간은 프레임 번호/명목 FPS이며 휴대폰 가변 FPS의 정확한 촬영 시각이 아닙니다.

## 구성 파일

- `comparison_engine.py`: 새 필터, 최종 판정, 박스/중심 계산, 공통 영상 합성.
- `video_frames.py`: 표본과 순차 처리 CSV 사이의 프레임 번호를 일치시키는 순차 디코딩 유틸리티.
- `test_01_*.py` ~ `test_08_*.py`: 각각 독립 실행 가능한 실험 진입점.
- `run_comparison.py`: 전체 프레임 비교, 8개 마스크 영상, CSV, 속도 요약, 출력 영상 검사.
- `annotations_phone.json`: 독립 수작업 정답 표본. 다른 영상에는 새 정답 파일을 만들어 사용합니다.
- `analyze_comparison.py`: 표본 평가, 합성 스트레스/부재 검사, 순위와 보고서.
- `build_overview.py`: 원본과 저장 CSV로 전체 8방식 종합 비교 영상 생성. 재검출하지 않습니다.
- `finalize_results.py`: 저장 CSV와 영상을 검증하고 요약 재생성. 집계만 중단된 경우 검출 재실행 없이 사용합니다.
- `test_pipeline.py`: 5프레임 영상을 만들어 EOF까지 처리하고 8개 출력 영상/CSV/요약/검출 잔류를 검사합니다.
- `verify_videos.py`: 개별 8영상과 종합 영상의 모든 프레임을 실제로 디코딩해 누락/잘림/크기를 검사합니다.
- `diagnose_candidates.py`: 색 마스크에서 타워 후보가 사라진 것인지, 후보는 있지만 큰 배경을 선택한 것인지 구분합니다.
- `test_comparison.py`: 빈 화면/회색/다른 색 배제, 최대 표적과 중심, 입력 변경 방지,
  사용하지 않는 필터 미계산, 이전 박스 잔류 방지, 홀수 해상도와 출력 화면 크기 검사.

최종 실험 결과는 `outputs/cv_comparison_phone/REPORT.md`에 있습니다.
[최종 해석과 추천](RESULTS_PHONE_20261006.md)에는 전체 영상 링크, 실패 원인, 순위의 한계가 있습니다.
`outputs/cv_comparison_phone_draft`는 합성부 최적화 전 중단한 초안이며 최종 비교에 사용하지 않습니다.

## 새 영상 재실험: 210419904

`KakaoTalk_20261006_210419904.mp4`는 별도 결과 폴더에 저장합니다. 기존 결과를 덮어쓰지 않습니다.
사용자 요청에 따라 큰 초록 배경 선택은 순위에서 제외하고, **타워 후보 자체가 최종 마스크에 남는지**를
우선 비교합니다. 최대영역 박스가 타워를 선택했는지는 참고 항목으로 분리합니다.

```powershell
.\.venv\Scripts\python.exe cv_tests\run_comparison.py --video img\KakaoTalk_20261006_210419904.mp4 --output outputs\cv_comparison_210419904
.\.venv\Scripts\python.exe cv_tests\evaluate_candidates.py --video img\KakaoTalk_20261006_210419904.mp4 --annotations cv_tests\annotations_210419904.json --output outputs\cv_comparison_210419904
.\.venv\Scripts\python.exe cv_tests\build_overview.py --output outputs\cv_comparison_210419904 --annotations cv_tests\annotations_210419904.json
.\.venv\Scripts\python.exe cv_tests\verify_videos.py --output outputs\cv_comparison_210419904
```

- `annotations_210419904.json`: 새 원본의 독립 육안 표본 48개. 영상 SHA256으로 잘못된 정답 파일 사용을 차단합니다.
- `evaluate_candidates.py`: 모든 윤곽 중 타워와 대응하는 후보를 찾습니다. 48개 표본 및 합성 스트레스 48건을 평가합니다.
  전체 비교가 끝난 뒤 실행하면 원본 순차 재검출 박스와 저장 CSV 박스도 대조합니다.
- `grid_references.py`: 타워 정답 박스를 육안으로 정할 때 축소 원본에 좌표 안내선을 추가합니다. 검출값은 사용하지 않습니다.
- `test_candidate_evaluation.py`: 큰 배경/진짜 타워 분리, 배경만 있는 장면, 작은 픽셀 잡음을 검사합니다.
- 새 결과: `outputs/cv_comparison_210419904/REPORT.md`, 종합 영상 1개, 개별 마스크 영상 8개.

표본 48개가 모두 성공하더라도 전체 4,297프레임 무손실 검출 보장은 아닙니다.
배경을 평가에서 제외하는 것과 실제 최대영역 검출기의 배경 선택을 고치는 것은 다릅니다.
이번 실험은 필터 비교이며 기존 ESP/라즈 제어 코드는 바꾸지 않습니다.

[최신 영상 결론과 모든 영상 링크](RESULTS_210419904.md)를 참고하세요.

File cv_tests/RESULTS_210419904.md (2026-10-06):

# 최신 영상 재비교 결과

입력은 `img/KakaoTalk_20261006_210419904.mp4`입니다. 1080×1920, 30fps,
총 4,297프레임을 8개 방식에 전부 넣었습니다. 기존 영상 결과는 덮어쓰지 않았습니다.
배경의 큰 초록 물체 선택은 순위에서 제외하고 실제 타워 후보가 마스크에 남는지 평가했습니다.
필터 설정은 이전 비교와 동일하게 유지했습니다.

## 결론

이번 영상에서는 **HSV 단독을 기본 후보로 선택해도 좋겠습니다.** 평균 검출 시간 7.54ms,
p99 14.79ms이고, 육안 정답 48개와 합성 스트레스 48개에서 모두 타워 후보가 남았습니다.
원본 해상도로 바로 검사하므로 코드가 단순하고 축소 탐색에서 작은 타워를 잃을 위험이 없습니다.

**속도 선두는 축소 탐색+원본 HSV입니다.** 평균 6.05ms, p99 12.38ms이고 위 표본 점수도 같습니다.
HSV 단독보다 평균 약 19.7% 빠릅니다. 다만 약 10px 폭의 먼 타워는 이 영상 표본으로
검증하지 못했습니다. 축소 후보가 사라지면 원본 ROI 검사도 시작되지 않는 한계가 있습니다.

4필터는 이 영상에서 표본 검출의 이점이 없었고 평균 33.49ms였습니다.
4필터와 Lab 제거 방식은 밝기를 절반으로 줄인 합성 표본 12개 중 3개에서 후보를 놓쳤습니다.
실제 어두운 면에서도 마스크가 일부 잘게 남는 모습을 확인했습니다. 여러 필터를 함께 쓰는 것이
항상 재현율을 높이지는 않습니다. BGR/ExG의 비슷한 초록 우세 조건이 여러 표로 반영되고,
4필터 3/4 투표와 3필터 2/3 투표의 기준 차이도 있습니다.

## 숫자 비교

시간은 이 Windows PC의 필터·마스크·윤곽·최대영역 선택 계산만 포함합니다.
디코딩, 화면 합성, 영상 저장은 제외했습니다. 초기 30프레임은 시간 집계에서 뺐습니다.
일부 평가 작업을 병행했으므로 완전 독점 CPU 조건은 아닙니다.

| 방식 | 평균 ms | p99 ms | 타워 후보 표본 | 합성 스트레스 |
|---|---:|---:|---:|---:|
| BGR+ExG+HSV+Lab | 33.49 | 57.80 | 48/48 | 45/48 |
| ExG 제거: BGR+HSV+Lab | 27.01 | 46.31 | 48/48 | 48/48 |
| Lab 제거: BGR+ExG+HSV | 23.97 | 43.22 | 48/48 | 45/48 |
| BGR 제거: ExG+HSV+Lab | 31.52 | 54.48 | 48/48 | 48/48 |
| HSV 단독 | 7.54 | 14.79 | 48/48 | 48/48 |
| 정규화 RGB | 22.67 | 35.38 | 48/48 | 48/48 |
| HSV AND 정규화 RGB | 30.46 | 51.15 | 48/48 | 48/48 |
| 축소 탐색+원본 HSV | 6.05 | 12.38 | 48/48 | 48/48 |

4필터 대비 평균 시간 감소는 ExG 제거 19.3%, Lab 제거 28.4%, BGR 제거 5.9%,
HSV 단독 77.5%, 축소 탐색+원본 HSV 81.9%입니다.
따라서 빠른 탐색이 목표라면 이 영상 기준으로는 3필터보다 HSV 계열이 훨씬 유리합니다.

## 검증 범위

- 정답은 순차 디코딩 원본을 보고 정한 48개 대략적인 박스입니다. 수정된 박스도 원본 이미지와 재대조했습니다.
- 원본 재검출 박스와 저장 CSV 박스가 48표본×8방식에서 일치하는지 검사했습니다.
- 합성 스트레스는 서로 다른 원본 12개에 밝기 0.5배/1.4배, 노이즈 σ12, Gaussian 5×5를 적용한 48건입니다.
- 이 영상의 모든 프레임에서 모든 방식이 어떤 색 영역은 검출했습니다. 이것이 전 프레임의 타워 정답을 뜻하지는 않습니다.
- 전체 4,297프레임의 수작업 정답이 없으므로 **한 번도 타워를 놓치지 않았다는 보장은 하지 않습니다.**
- 표본 정답 박스의 최소 폭은 원본 기준 약 51px입니다. 목표인 약 10px 폭은 별도 검증이 필요합니다.
- 30fps 휴대폰 영상 실험입니다. 라즈베리파이5의 실제 카메라 50fps 입력/처리/UART 성능은 아직 검증하지 않았습니다.
- 빈 화면·색 구분·최대영역·이전 박스 잔류·입력 보존 등을 검사하는 회귀 테스트 7개,
  배경 제외 후보 검사 3개, 5프레임 전체 저장 파이프라인 검사를 통과했습니다.

## 영상과 상세 데이터

[8방식 종합 비교 영상](../outputs/cv_comparison_210419904/00_all_methods_overview.mp4)

- [4필터 성분 및 최종 마스크](../outputs/cv_comparison_210419904/01_four_vote.mp4)
- [ExG 제거 성분 및 최종 마스크](../outputs/cv_comparison_210419904/02_no_exg.mp4)
- [Lab 제거 성분 및 최종 마스크](../outputs/cv_comparison_210419904/03_no_lab.mp4)
- [BGR 제거 성분 및 최종 마스크](../outputs/cv_comparison_210419904/04_no_bgr.mp4)
- [HSV 단독 마스크](../outputs/cv_comparison_210419904/05_hsv.mp4)
- [정규화 RGB 마스크](../outputs/cv_comparison_210419904/06_normalized.mp4)
- [HSV+정규화 RGB 마스크](../outputs/cv_comparison_210419904/07_hsv_normalized.mp4)
- [축소 탐색+원본 HSV 마스크](../outputs/cv_comparison_210419904/08_hsv_cascade.mp4)
- [평가 기준 및 상세 보고서](../outputs/cv_comparison_210419904/REPORT.md)
- [실행 방법과 파일 설명](README.md)

`metrics.csv`에 전체 프레임별 연산시간/박스/중심/면적이 있고,
`candidate_evaluation.csv`에는 표본별 원본 및 스트레스 후보 정답 여부가 있습니다.
`video_verification.json`은 개별 8개와 종합 1개의 전 프레임 재디코딩 검사 결과입니다.
`labels/`에는 정답 검토 이미지, `references/`에는 순차 디코딩 원본 표본과 좌표 안내 이미지가 있습니다.

화면 확인만 다시 하려면 프로젝트 루트에서 다음을 실행합니다. 단독 실행 파일은 영상 경로를
위치 인자로 받습니다(`--video`가 아닙니다). 저장된 비교 결과를 덮어쓰지 않도록 별도 출력 경로를 씁니다.

```powershell
.\.venv\Scripts\python.exe cv_tests\test_05_hsv.py img\KakaoTalk_20261006_210419904.mp4 --show --output outputs\hsv_210419904_preview.mp4
```

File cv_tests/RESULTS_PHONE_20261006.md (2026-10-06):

# 휴대폰 컬러타워 영상 비교 — 최종 분석

## 결론

이번 영상에서 검출 성능과 시간을 함께 보면 **BGR + ExG + HSV(03번, Lab 제거)**가
4필터보다 나았습니다. 정답 표본/스트레스 성적은 같고 평균 연산시간은 30.54ms → 21.70ms로
**28.96% 감소**했습니다. 하지만 p99 26.17ms여서 이 PC의 OpenCV 1스레드 조건에서는
검출만으로도 안정적인 50Hz 예산을 만족하지 못합니다.

**50Hz 연산 예산 안의 후보는 08번 HSV 축소 탐색→원본 ROI 검사**입니다.
평균 6.06ms, p99 9.49ms이며, HSV 단독 평균 6.57ms보다 0.51ms(7.73%) 빠릅니다.
두 방식의 실제 타워 정답 표본 수는 29/45로 같습니다. 합성 스트레스는 08번 28/48,
HSV 단독 27/48로 차이가 작아서 압도적 우위라고 해석하면 안 됩니다.
코드의 단순함과 아주 작은 표적의 축소 손실을 우선하면 HSV 단독을 기준으로 유지해도 됩니다.

**어느 방식도 한 번도 놓치지 않는 타워 추적을 달성하지 못했습니다.**
이 실험은 시간적 추적/형태 검증 없이 가장 큰 색 영역을 고르는 기준 실험입니다.
실행 오류나 영상 누락과 알고리즘의 오선택을 구분해야 합니다.

## 최종 측정값

같은 원본 1080×1920, 4,280프레임 전체, OpenCV 4.12.0 1스레드입니다.
처음 30프레임은 시간 통계에서 제외했습니다. 숫자는 PC 측정값이고 라즈5 성능이 아닙니다.
검출 연산에는 필터·마스크 합성·닫힘·윤곽·최대 표적 선택이 포함됩니다.
디코딩/영상 합성/저장 비용은 별도이며 아래 시간에 포함되지 않습니다.

| 방식 | 평균 ms | p99 ms | 표본에서 실제 타워 / 45 | 다른 물체 선택 | 스트레스 정답 / 48 |
|---|---:|---:|---:|---:|---:|
| 01: BGR+ExG+HSV+Lab, 3/4 | 30.54 | 35.15 | 32 | 13 | 34 |
| 02: BGR+HSV+Lab, 2/3 | 24.64 | 29.18 | 29 | 16 | 29 |
| 03: BGR+ExG+HSV, 2/3 | 21.70 | 26.17 | 32 | 13 | 34 |
| 04: ExG+HSV+Lab, 2/3 | 28.70 | 33.02 | 29 | 16 | 28 |
| 05: HSV 단독 | 6.57 | 9.86 | 29 | 16 | 27 |
| 06: 정규화 RGB | 22.70 | 26.97 | 30 | 15 | 29 |
| 07: HSV AND 정규화 RGB | 29.32 | 34.46 | 30 | 15 | 29 |
| 08: 축소 탐색→원본 HSV | 6.06 | 9.49 | 29 | 16 | 28 |

ExG 제거는 19.31%, Lab 제거는 28.96%, BGR 마스크 제거는 6.03%의 평균 시간 감소였습니다.
이는 이번 구현/해상도/영상의 전체 검출시간 비교이지 필터별 보편적인 계산비용 순위가 아닙니다.
특히 BGR 마스크를 빼도 ExG의 채널 차이 계산이 필요하므로 감소폭이 작습니다.
정규화 RGB도 이 float32 변환 구현에서는 HSV보다 느렸습니다. 나눗셈이 없다고 빠른 것은 아니었습니다.

3필터의 2/3과 4필터의 3/4는 같은 판정이 아닙니다. BGR와 ExG는 독립 정보도 아닙니다.
이번에 ExG 제거의 성적이 내려간 것은 ExG가 새로운 정보를 준다는 증명이 아닙니다.
현재 투표에서는 BGR 계열 초록 우세에 중복 가중치가 있었고, ExG를 빼면 HSV+Lab만으로도
2표를 얻어 그 조건을 우회할 수 있습니다. 중복 제거와 판정 규칙 재설계는 구분해야 합니다.
Lab 제거와 4필터는 정답 성적이 같았지만, 전체 4,280프레임 중 최종 선택 박스가 다른 프레임은
15개이고 최종 마스크 픽셀 수가 다른 프레임은 167개였습니다. 완전히 동일한 알고리즘은 아닙니다.

## 실패 원인: 색이 없어졌는가, 후보를 잘못 골랐는가

별도 진단에서는 최종 마스크의 모든 윤곽을 검사하고, 타워 정답 박스와 맞는 후보가 있는지 확인했습니다.

| 방식 | 타워 후보가 있는 표본 / 45 | 그 후보 대신 배경을 선택 | 정답 기준에 맞는 별도 후보 없음 |
|---|---:|---:|---:|
| 4필터 | 43 | 11 | 2 |
| Lab 제거 3필터 | 43 | 11 | 2 |
| HSV 단독 | 44 | 15 | 1 |
| 축소→원본 HSV | 44 | 15 | 1 |

따라서 현재 문제의 상당 부분은 HSV가 타워 색을 전혀 못 보는 것이 아닙니다.
**타워보다 큰 초록 매트/식물 등의 영역을 선택하는 문제**입니다.
약 6.07초(프레임 182)의 종합 영상에서 모든 방식이 작은 타워 대신 왼쪽 초록 매트를 선택하는 모습을 볼 수 있습니다.
종합 영상의 노란 박스는 수작업 정답, 초록 박스는 검출 결과, 빨간 십자는 검출 중심입니다.

별도 후보가 없다는 판정도 곧바로 색 신호가 완전히 없어졌다는 뜻은 아닙니다.
타워와 초록 배경이 같은 연결 영역으로 붙어 정답 박스 조건을 만족하지 못할 수도 있습니다.
HSV의 해당 진단 표본은 프레임 3732입니다. 후보 선택과 붙은 영역 분리가 다음 개선 대상입니다.
이번 비교에서는 결과를 보고 임계값이나 형태 조건을 새로 튜닝해 순위를 유리하게 바꾸지 않았습니다.

## 자체 기준과 검증

- 원본을 순차 디코딩해 육안으로 정한 48개 표본: 타워 있음 45, 화면 밖 3.
- 중심점이 정답 박스의 15% 여유 안에 있고 IoU≥0.25면 정답. 박스는 육안 추정이며 정밀 분할 정답이 아닙니다.
- 표본 12개 × 밝기 0.5배/1.4배, 노이즈 σ12, 5×5 흐림 = 스트레스 48개.
- 타워 주변을 회색으로 지운 45개 합성 부재 실험. 실제 대회 부재 영상의 오검출률은 아닙니다.
- 모든 방식에서 표본 45개 중 '아무것도 검출 안 함'은 0개지만 다른 물체를 잡은 사례는 13~16개입니다.
  이 때문에 전체 검출 유무만으로 성공률을 계산하지 않았습니다.
- 자연 부재 표본 3개에서 4필터/03번은 오검출 0, HSV/08번은 오검출 2였습니다.
  표본이 너무 적어 일반적인 오검출 확률을 추정할 수 없습니다.
- 7개 회귀 테스트, 5프레임 전체 파이프라인 EOF/CSV/8영상 테스트 통과.
- 8개 마스크 영상 + 1개 종합 영상 각각 4,280프레임을 다시 모두 디코딩해 검사.

검증 도중 EOF 뒤 `frame=None`을 참조하는 집계 오류를 찾아 최종화 기능을 분리해 수정했습니다.
이미 저장된 전체 CSV/영상은 유지하고 다시 검증해서 요약을 생성했습니다.
또한 이 휴대폰 영상의 seek 결과가 순차 디코딩과 다른 것을 발견해 모든 정답/스트레스/후보 진단을
순차 디코딩으로 수정했습니다. 프레임이 어긋난 초기 정답과 중간 점수는 최종 평가에서 폐기했습니다.
최종 점수와 이 문서만 기준으로 사용합니다.

이 영상 하나와 48개 표본만으로 대회장 조명, 실제 Pi Camera 3 Wide의 게인 노이즈,
폭 약 10픽셀의 원거리 성능, 라즈5 50Hz를 보장할 수는 없습니다.
필터 연산과 UART 송신 주기 분리는 나중의 실제 라즈 적용 단계이며 이번 파일에는 UART가 없습니다.

## 결과 보기

- [8가지 종합 비교 영상](D:/C_ROBOT/outputs/cv_comparison_phone/00_all_methods_overview.mp4)
- [4필터 + 개별 마스크](D:/C_ROBOT/outputs/cv_comparison_phone/01_four_vote.mp4)
- [ExG 제거 + 개별 마스크](D:/C_ROBOT/outputs/cv_comparison_phone/02_no_exg.mp4)
- [Lab 제거 + 개별 마스크](D:/C_ROBOT/outputs/cv_comparison_phone/03_no_lab.mp4)
- [BGR 제거 + 개별 마스크](D:/C_ROBOT/outputs/cv_comparison_phone/04_no_bgr.mp4)
- [HSV 단독 + 마스크](D:/C_ROBOT/outputs/cv_comparison_phone/05_hsv.mp4)
- [정규화 RGB + 마스크](D:/C_ROBOT/outputs/cv_comparison_phone/06_normalized.mp4)
- [HSV AND 정규화 + 마스크](D:/C_ROBOT/outputs/cv_comparison_phone/07_hsv_normalized.mp4)
- [축소 탐색→원본 HSV + 마스크](D:/C_ROBOT/outputs/cv_comparison_phone/08_hsv_cascade.mp4)
- [전체 수치 보고서](D:/C_ROBOT/outputs/cv_comparison_phone/REPORT.md)
- [코드 구조·실행법·설정 설명](D:/C_ROBOT/cv_tests/README.md)

원본 소리는 저장하지 않았습니다. 모든 영상은 같은 프레임 순서와 약 29.979fps로 저장했습니다.
표시 초는 프레임 번호/명목 FPS입니다. 휴대폰 가변 FPS의 정확한 촬영 타임스탬프는 아닙니다.
정답 표시는 48개 표본에만 있으며, 다른 프레임의 `FOUND - UNLABELED`는 정답 확인이 아닙니다.
CSV/JSON과 영상은 `outputs/cv_comparison_phone`에 있습니다. 영상/결과 폴더는 기존 Git 제외 규칙을 유지합니다.

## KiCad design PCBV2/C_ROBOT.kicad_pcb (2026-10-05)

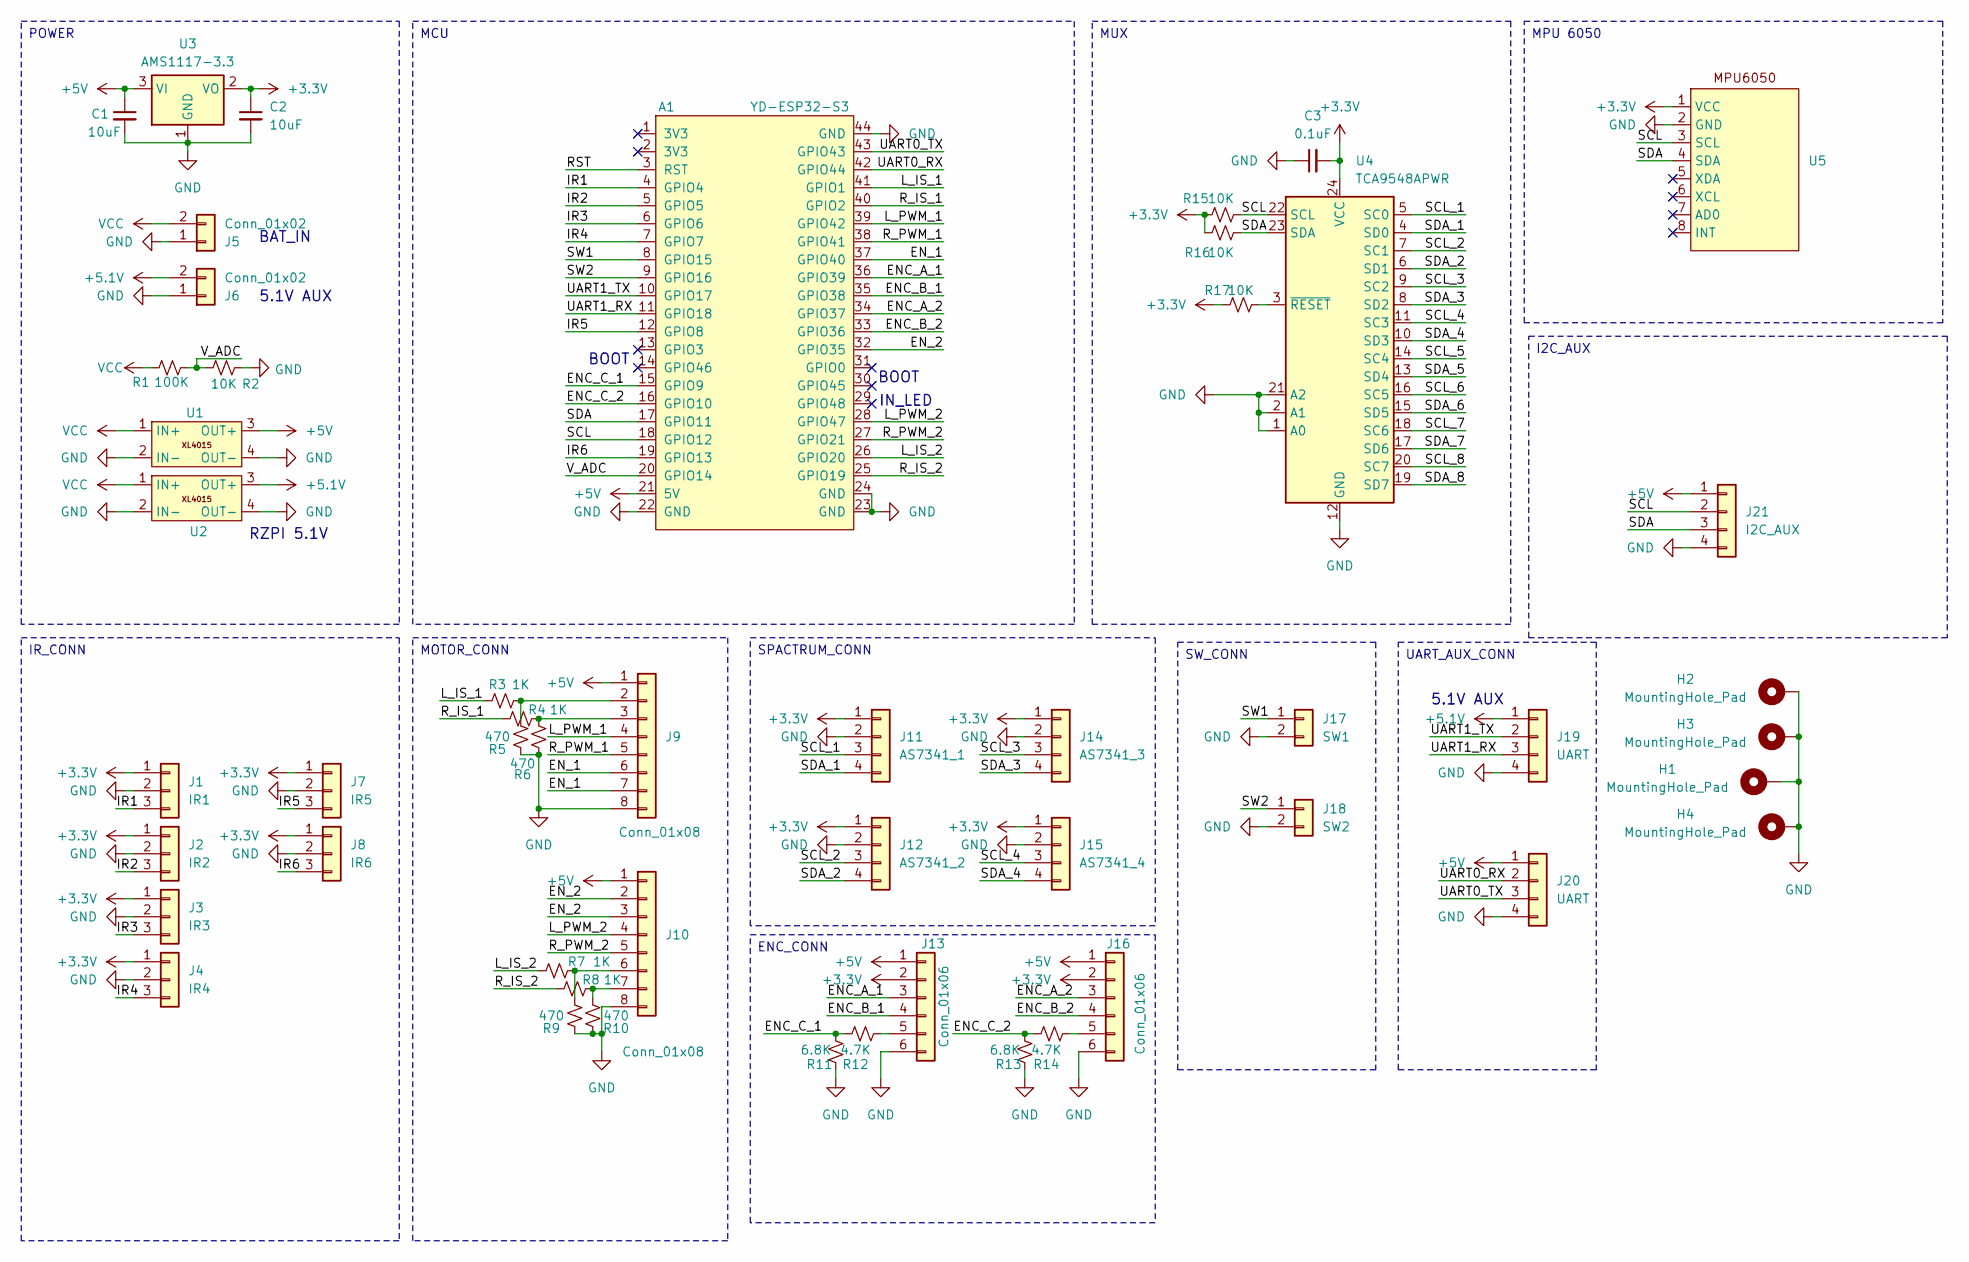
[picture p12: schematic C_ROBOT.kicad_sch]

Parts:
A1: YD-ESP32-S3
C1, C2: 10uF; C_0805_2012Metric_Pad1.18x1.45mm_HandSolder
C3: 0.1uF; C_0805_2012Metric_Pad1.18x1.45mm_HandSolder
H1, H2, H3, H4: MountingHole_Pad; MountingHole_3.2mm_M3_DIN965_Pad
J1: IR1; Molex_SPOX_5267-03A_1x03_P2.50mm_Vertical
J2: IR2; Molex_SPOX_5267-03A_1x03_P2.50mm_Vertical
J3: IR3; Molex_SPOX_5267-03A_1x03_P2.50mm_Vertical
J4: IR4; Molex_SPOX_5267-03A_1x03_P2.50mm_Vertical
J5: Conn_01x02; AMASS_XT30U-M_1x02_P5.0mm_Vertical
J6: Conn_01x02; Molex_SPOX_5267-02A_1x02_P2.50mm_Vertical
J7: IR5; Molex_SPOX_5267-03A_1x03_P2.50mm_Vertical
J8: IR6; Molex_SPOX_5267-03A_1x03_P2.50mm_Vertical
J9, J10: Conn_01x08; Molex_SPOX_5267-08A_1x08_P2.50mm_Vertical
J11: AS7341_1; Molex_SPOX_5267-04A_1x04_P2.50mm_Vertical
J12: AS7341_2; Molex_SPOX_5267-04A_1x04_P2.50mm_Vertical
J13, J16: Conn_01x06; Molex_SPOX_5267-06A_1x06_P2.50mm_Vertical
J14: AS7341_3; Molex_SPOX_5267-04A_1x04_P2.50mm_Vertical
J15: AS7341_4; Molex_SPOX_5267-04A_1x04_P2.50mm_Vertical
J17: SW1; Molex_SPOX_5267-02A_1x02_P2.50mm_Vertical
J18: SW2; Molex_SPOX_5267-02A_1x02_P2.50mm_Vertical
J19, J20: UART; Molex_SPOX_5267-04A_1x04_P2.50mm_Vertical
J21: I2C_AUX; Molex_SPOX_5267-04A_1x04_P2.50mm_Vertical
R1: 100K; R_0603_1608Metric
R2, R15, R16, R17: 10K; R_0603_1608Metric
R3, R4, R7, R8: 1K; R_0603_1608Metric
R5, R6, R9, R10: 470; R_0603_1608Metric
R11, R13: 6.8K; R_0603_1608Metric
R12, R14: 4.7K; R_0603_1608Metric
U1, U2: XL4015
U3: AMS1117-3.3; SOT-223-3_TabPin2
U4: TCA9548APWR; TSSOP-24_4.4x7.8mm_P0.65mm
U5: MPU6050

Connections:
+3.3V: C2.1, C3.2, J1.1, J2.1, J3.1, J4.1, J7.1, J8.1, J11.1, J12.1, J13.2, J14.1, J15.1, J16.2, R15.1, R16.1, R17.1, U3.2 (VO), U4.24 (VCC), U5.1 (VCC)
+5.1V: J6.2, J19.1, U2.3 (OUT+)
+5V: A1.21 (5V), C1.1, J9.1, J10.1, J13.1, J16.1, J20.1, J21.1, U1.3 (OUT+), U3.3 (VI)
/ENC_A_1: A1.36 (GPIO39), J13.3
/ENC_A_2: A1.34 (GPIO37), J16.3
/ENC_B_1: A1.35 (GPIO38), J13.4
/ENC_B_2: A1.33 (GPIO36), J16.4
/ENC_C_1: A1.15 (GPIO9), R11.2, R12.2
/ENC_C_2: A1.16 (GPIO10), R13.2, R14.2
/EN_1: A1.37 (GPIO40), J9.6, J9.7
/EN_2: A1.32 (GPIO35), J10.2, J10.3
/IR1: A1.4 (GPIO4), J1.3
/IR2: A1.5 (GPIO5), J2.3
/IR3: A1.6 (GPIO6), J3.3
/IR4: A1.7 (GPIO7), J4.3
/IR5: A1.12 (GPIO8), J7.3
/IR6: A1.19 (GPIO13), J8.3
/L_IS_1: A1.41 (GPIO1), R3.2
/L_IS_2: A1.26 (GPIO20), R7.2
/L_PWM_1: A1.39 (GPIO42), J9.4
/L_PWM_2: A1.28 (GPIO47), J10.4
/RST: A1.3 (RST)
/R_IS_1: A1.40 (GPIO2), R4.2
/R_IS_2: A1.25 (GPIO19), R8.2
/R_PWM_1: A1.38 (GPIO41), J9.5
/R_PWM_2: A1.27 (GPIO21), J10.5
/SCL: A1.18 (GPIO12), J21.2, R15.2, U4.22 (SCL), U5.3 (SCL)
/SCL_1: J11.3, U4.5 (SC0)
/SCL_2: J12.3, U4.7 (SC1)
/SCL_3: J14.3, U4.9 (SC2)
/SCL_4: J15.3, U4.11 (SC3)
/SCL_5: U4.14 (SC4)
/SCL_6: U4.16 (SC5)
/SCL_7: U4.18 (SC6)
/SCL_8: U4.20 (SC7)
/SDA: A1.17 (GPIO11), J21.3, R16.2, U4.23 (SDA), U5.4 (SDA)
/SDA_1: J11.4, U4.4 (SD0)
/SDA_2: J12.4, U4.6 (SD1)
/SDA_3: J14.4, U4.8 (SD2)
/SDA_4: J15.4, U4.10 (SD3)
/SDA_5: U4.13 (SD4)
/SDA_6: U4.15 (SD5)
/SDA_7: U4.17 (SD6)
/SDA_8: U4.19 (SD7)
/SW1: A1.8 (GPIO15), J17.1
/SW2: A1.9 (GPIO16), J18.1
/UART0_RX: A1.42 (GPIO44), J20.2
/UART0_TX: A1.43 (GPIO43), J20.3
/UART1_RX: A1.11 (GPIO18), J19.3
/UART1_TX: A1.10 (GPIO17), J19.2
/V_ADC: A1.20 (GPIO14), R1.1, R2.2
GND: A1.22 (GND), A1.23 (GND), A1.24 (GND), A1.44 (GND), C1.2, C2.2, C3.1, H1.1 (1_1), H2.1 (1_1), H3.1 (1_1), H4.1 (1_1), J1.2, J2.2, J3.2, J4.2, J5.1, J6.1, J7.2, J8.2, J9.8, J10.8, J11.2, J12.2, J13.6, J14.2, J15.2, J16.6, J17.2, J18.2, J19.4, J20.4, J21.4, R2.1, R5.1, R6.1, R9.1, R10.1, R11.1, R13.1, U1.2 (IN-), U1.4 (OUT-), U2.2 (IN-), U2.4 (OUT-), U3.1 (GND), U4.1 (A0), U4.2 (A1), U4.12 (GND), U4.21 (A2), U5.2 (GND)
unnamed: J9.2, R3.1, R5.2
unnamed: J9.3, R4.1, R6.2
unnamed: J10.6, R7.1, R9.2
unnamed: J10.7, R8.1, R10.2
unnamed: J13.5, R12.1
unnamed: J16.5, R14.1
unnamed: R17.2, U4.3 (~RESET)
VCC: J5.2, R1.2, U1.1 (IN+), U2.1 (IN+)

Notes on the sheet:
BAT_IN
BOOT
RZPI 5.1V
5.1V AUX
IN_LED
I2C_AUX
IR_CONN
MPU 6050
MOTOR_CONN
ENC_CONN
UART_AUX_CONN
MUX
MCU
POWER
SW_CONN
SPACTRUM_CONN

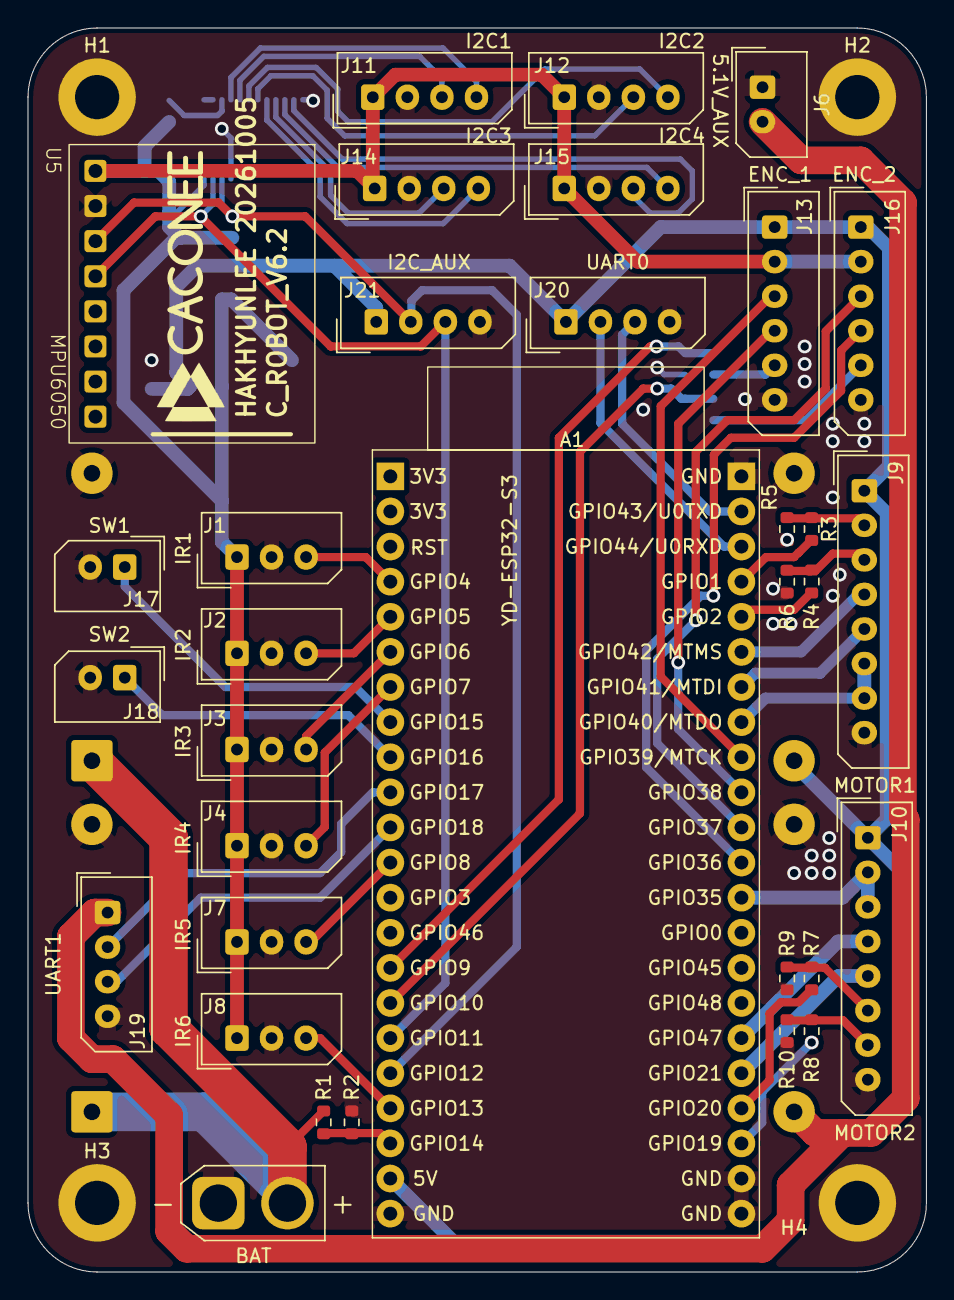
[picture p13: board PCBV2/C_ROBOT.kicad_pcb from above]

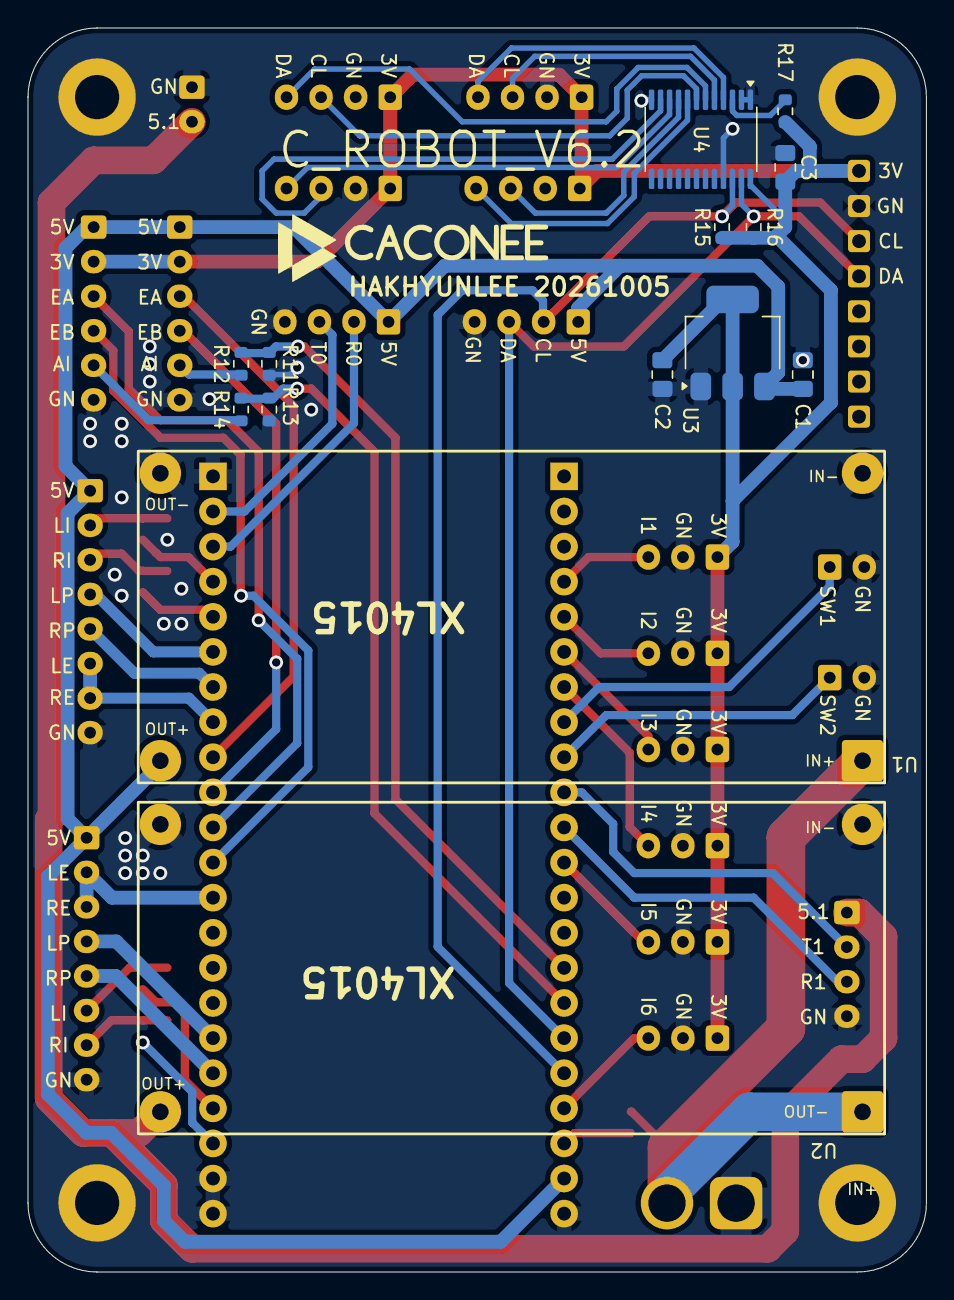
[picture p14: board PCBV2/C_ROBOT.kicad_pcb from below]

Board: 2 copper layers, 65.0 x 90.0 mm, 51 parts (14 on the bottom side), 51 nets.

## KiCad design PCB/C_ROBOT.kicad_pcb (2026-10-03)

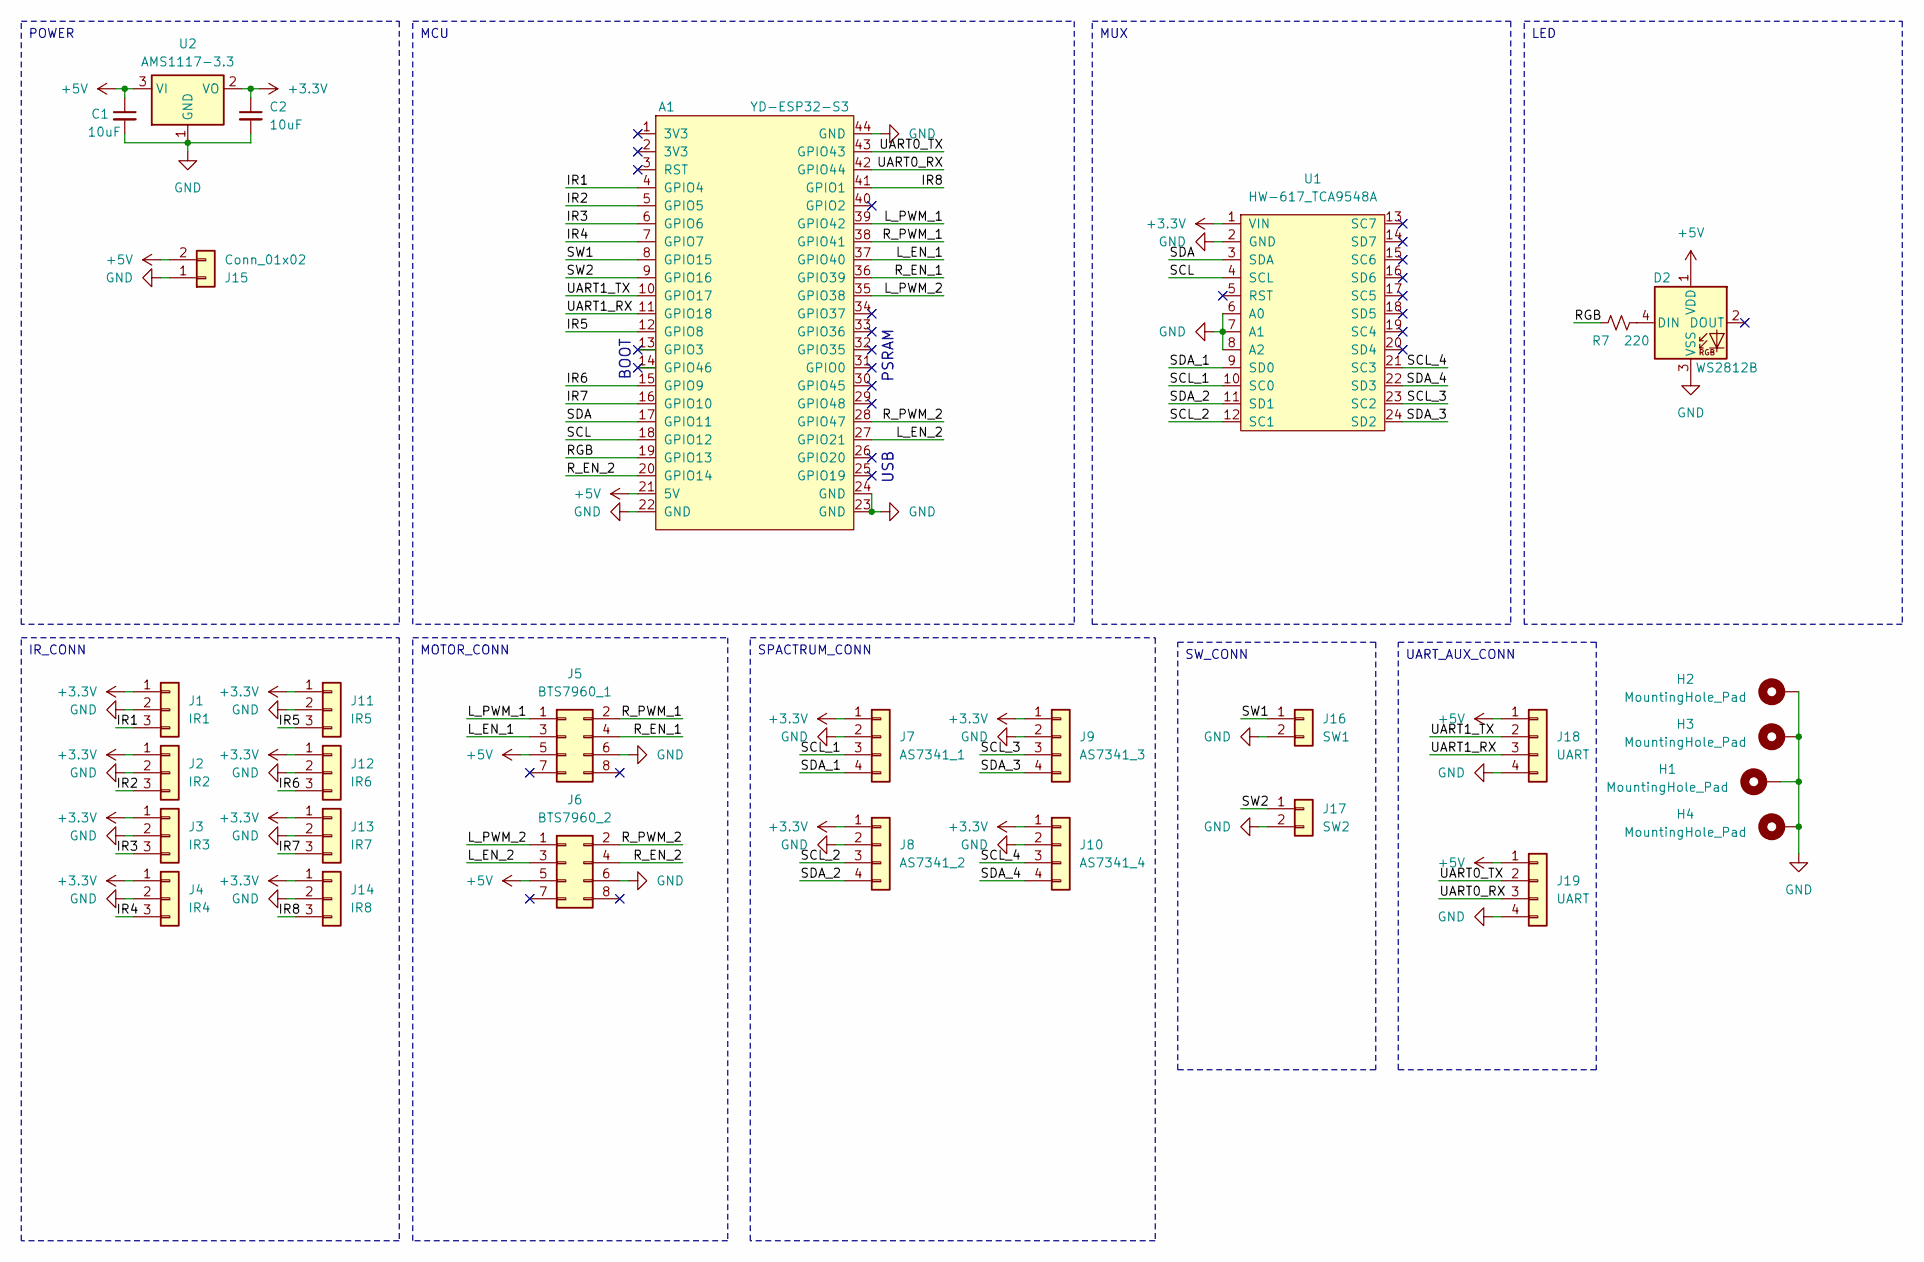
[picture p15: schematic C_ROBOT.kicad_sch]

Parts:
A1: YD-ESP32-S3
C1, C2: 10uF; C_0805_2012Metric_Pad1.18x1.45mm_HandSolder
D2: WS2812B; LED_WS2812B_PLCC4_5.0x5.0mm_P3.2mm
H1, H2, H3, H4: MountingHole_Pad; MountingHole_3.2mm_M3_DIN965_Pad
J1: IR1; Molex_SPOX_5267-03A_1x03_P2.50mm_Vertical
J2: IR2; Molex_SPOX_5267-03A_1x03_P2.50mm_Vertical
J3: IR3; Molex_SPOX_5267-03A_1x03_P2.50mm_Vertical
J4: IR4; Molex_SPOX_5267-03A_1x03_P2.50mm_Vertical
J5: BTS7960_1; Molex_SPOX_5267-06A_1x06_P2.50mm_Vertical
J6: BTS7960_2; Molex_SPOX_5267-06A_1x06_P2.50mm_Vertical
J7: AS7341_1; Molex_SPOX_5267-04A_1x04_P2.50mm_Vertical
J8: AS7341_2; Molex_SPOX_5267-04A_1x04_P2.50mm_Vertical
J9: AS7341_3; Molex_SPOX_5267-04A_1x04_P2.50mm_Vertical
J10: AS7341_4; Molex_SPOX_5267-04A_1x04_P2.50mm_Vertical
J11: IR5; Molex_SPOX_5267-03A_1x03_P2.50mm_Vertical
J12: IR6; Molex_SPOX_5267-03A_1x03_P2.50mm_Vertical
J13: IR7; Molex_SPOX_5267-03A_1x03_P2.50mm_Vertical
J14: IR8; Molex_SPOX_5267-03A_1x03_P2.50mm_Vertical
J15: Conn_01x02; AMASS_XT30U-M_1x02_P5.0mm_Vertical
J16: SW1; Molex_SPOX_5267-02A_1x02_P2.50mm_Vertical
J17: SW2; Molex_SPOX_5267-02A_1x02_P2.50mm_Vertical
J18, J19: UART; Molex_SPOX_5267-04A_1x04_P2.50mm_Vertical
R7: 220; R_0805_2012Metric_Pad1.20x1.40mm_HandSolder
U1: HW-617_TCA9548A; HW-617
U2: AMS1117-3.3; SOT-223-3_TabPin2

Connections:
+3.3V: C2.1, J1.1, J2.1, J3.1, J4.1, J7.1, J8.1, J9.1, J10.1, J11.1, J12.1, J13.1, J14.1, U1.1 (VIN), U2.2 (VO)
+5V: A1.21 (5V), C1.1, D2.1 (VDD), J5.5, J6.5, J15.2, J18.1, J19.1, U2.3 (VI)
/IR1: A1.4 (GPIO4), J1.3
/IR2: A1.5 (GPIO5), J2.3
/IR3: A1.6 (GPIO6), J3.3
/IR4: A1.7 (GPIO7), J4.3
/IR5: A1.12 (GPIO8), J11.3
/IR6: A1.15 (GPIO9), J12.3
/IR7: A1.16 (GPIO10), J13.3
/IR8: A1.41 (GPIO1), J14.3
/L_EN_1: A1.37 (GPIO40), J5.3
/L_EN_2: A1.27 (GPIO21), J6.3
/L_PWM_1: A1.39 (GPIO42), J5.1
/L_PWM_2: A1.35 (GPIO38), J6.1
/RGB: A1.19 (GPIO13), R7.2
/R_EN_1: A1.36 (GPIO39), J5.4
/R_EN_2: A1.20 (GPIO14), J6.4
/R_PWM_1: A1.38 (GPIO41), J5.2
/R_PWM_2: A1.28 (GPIO47), J6.2
/SCL: A1.18 (GPIO12), U1.4 (SCL)
/SCL_1: J7.3, U1.10 (SC0)
/SCL_2: J8.3, U1.12 (SC1)
/SCL_3: J9.3, U1.23 (SC2)
/SCL_4: J10.3, U1.21 (SC3)
/SDA: A1.17 (GPIO11), U1.3 (SDA)
/SDA_1: J7.4, U1.9 (SD0)
/SDA_2: J8.4, U1.11 (SD1)
/SDA_3: J9.4, U1.24 (SD2)
/SDA_4: J10.4, U1.22 (SD3)
/SW1: A1.8 (GPIO15), J16.1
/SW2: A1.9 (GPIO16), J17.1
/UART0_RX: A1.42 (GPIO44), J19.3
/UART0_TX: A1.43 (GPIO43), J19.2
/UART1_RX: A1.11 (GPIO18), J18.3
/UART1_TX: A1.10 (GPIO17), J18.2
GND: A1.22 (GND), A1.23 (GND), A1.24 (GND), A1.44 (GND), C1.2, C2.2, D2.3 (VSS), H1.1 (1_1), H2.1 (1_1), H3.1 (1_1), H4.1 (1_1), J1.2, J2.2, J3.2, J4.2, J5.6, J6.6, J7.2, J8.2, J9.2, J10.2, J11.2, J12.2, J13.2, J14.2, J15.1, J16.2, J17.2, J18.4, J19.4, U1.2 (GND), U1.6 (A0), U1.7 (A1), U1.8 (A2), U2.1 (GND)
unnamed: D2.4 (DIN), R7.1

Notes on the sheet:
BOOT
USB
PSRAM
IR_CONN
MOTOR_CONN
UART_AUX_CONN
MUX
MCU
POWER
SW_CONN
LED
SPACTRUM_CONN

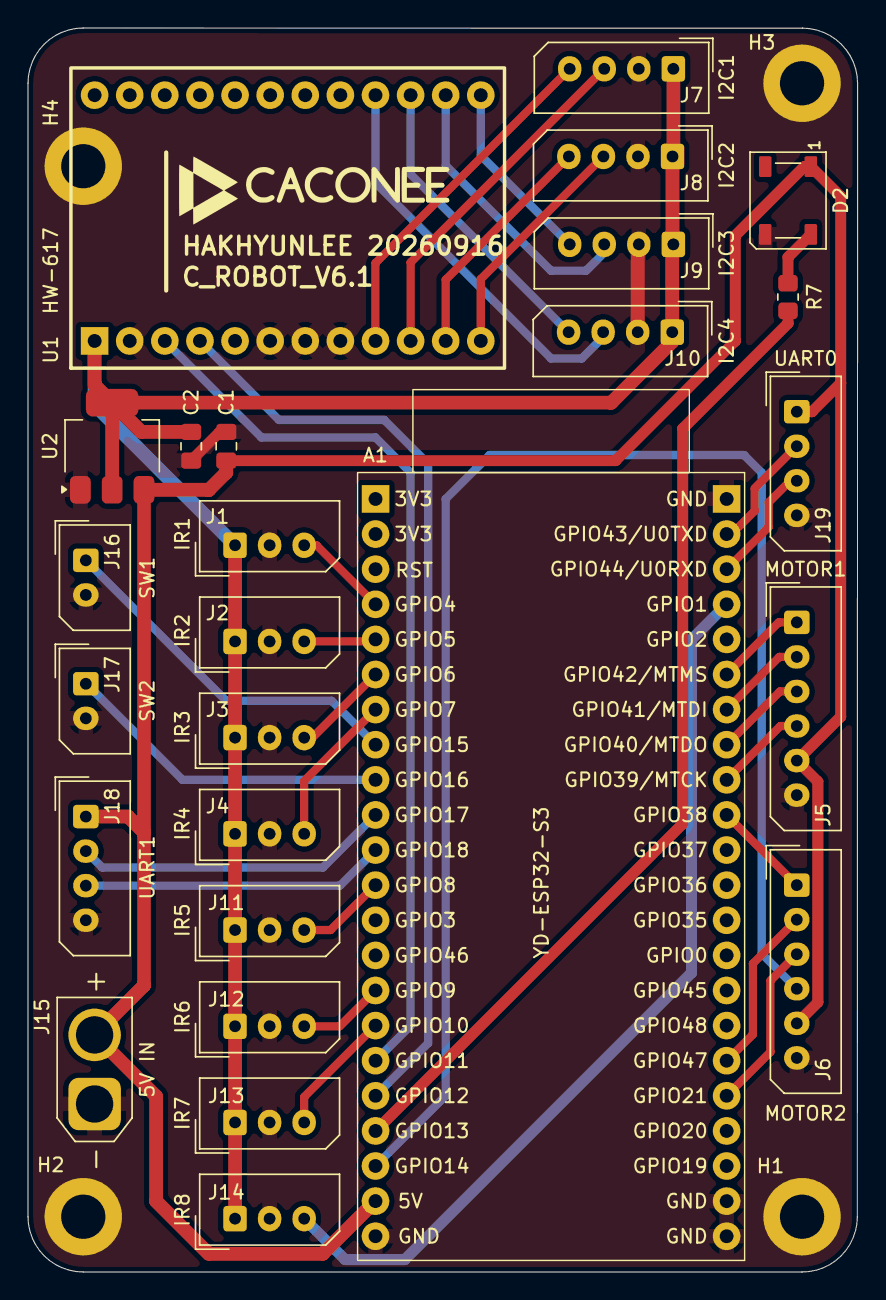
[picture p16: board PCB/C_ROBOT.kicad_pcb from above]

Board: 2 copper layers, 60.0 x 90.0 mm, 30 parts (0 on the bottom side), 37 nets.

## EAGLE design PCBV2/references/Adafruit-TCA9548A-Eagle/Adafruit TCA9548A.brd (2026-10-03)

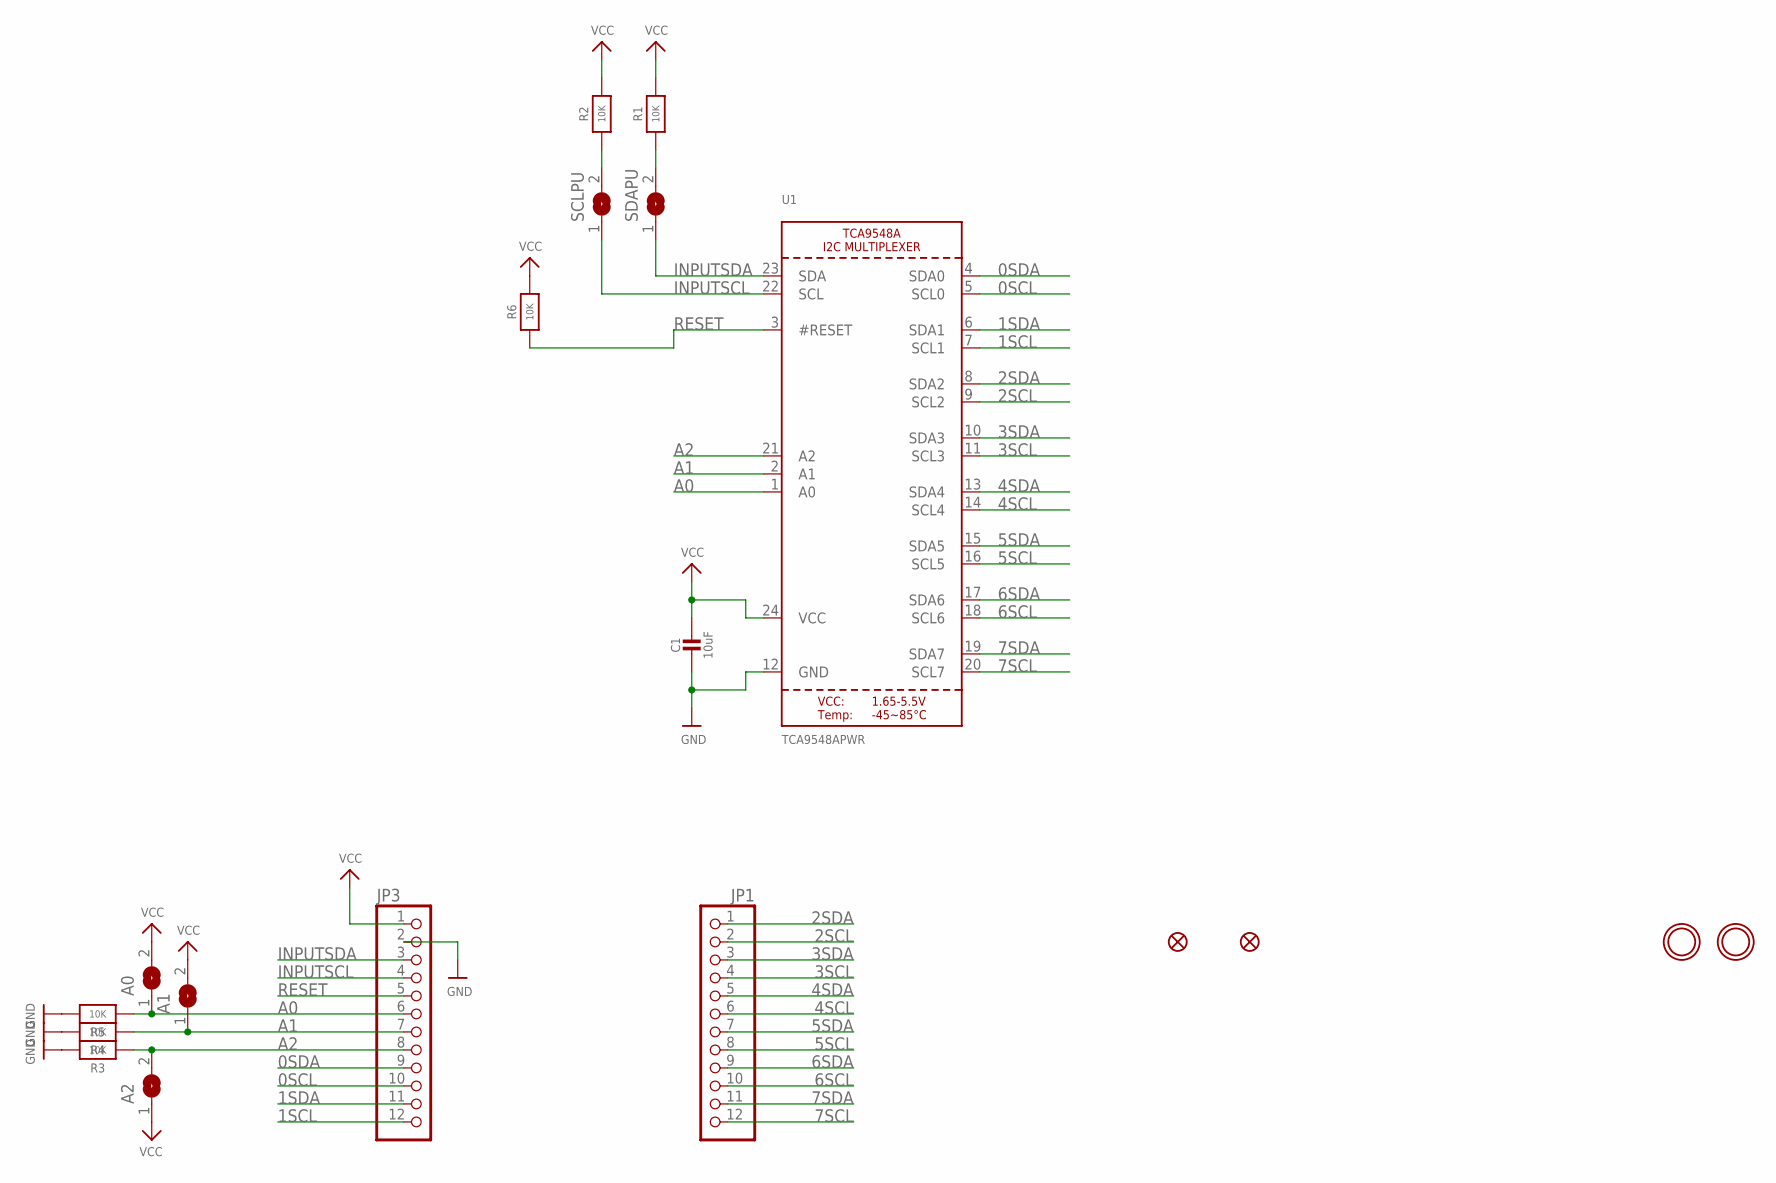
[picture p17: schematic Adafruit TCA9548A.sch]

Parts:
A0, A1, A2: SOLDERJUMPER; SOLDERJUMPER_ARROW_NOPASTE
C1: 10uF; 0805-NO
FID1, FID3: FIDUCIAL""; FIDUCIAL_1MM
JP1, JP3: HEADER-1X12; 1X12_ROUND
R1, R2, R3, R4, R5: 10K; 0805-NO
R6: 10K; _0805MP
SCLPU: SOLDERJUMPERCLOSED; SOLDERJUMPER_CLOSEDWIRE
SDAPU: SOLDERJUMPERCLOSED; SOLDERJUMPER_CLOSEDWIRE
U1: TCA9548APWR; TSSOP24
U$4, U$5: MOUNTINGHOLE2.5; MOUNTINGHOLE_2.5_PLATED

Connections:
0SCL: JP3.10, U1.5 (SCL0)
0SDA: JP3.9, U1.4 (SDA0)
1SCL: JP3.12, U1.7 (SCL1)
1SDA: JP3.11, U1.6 (SDA1)
2SCL: JP1.2, U1.9 (SCL2)
2SDA: JP1.1, U1.8 (SDA2)
3SCL: JP1.4, U1.11 (SCL3)
3SDA: JP1.3, U1.10 (SDA3)
4SCL: JP1.6, U1.14 (SCL4)
4SDA: JP1.5, U1.13 (SDA4)
5SCL: JP1.8, U1.16 (SCL5)
5SDA: JP1.7, U1.15 (SDA5)
6SCL: JP1.10, U1.18 (SCL6)
6SDA: JP1.9, U1.17 (SDA6)
7SCL: JP1.12, U1.20 (SCL7)
7SDA: JP1.11, U1.19 (SDA7)
A0: A0.1, JP3.6, R5.1, U1.1 (A0)
A1: A1.1, JP3.7, R4.1, U1.2 (A1)
A2: A2.2, JP3.8, R3.1, U1.21 (A2)
GND: C1.2, JP3.2, R3.2, R4.2, R5.2, U1.12 (GND)
INPUTSCL: JP3.4, SCLPU.1, U1.22 (SCL)
INPUTSDA: JP3.3, SDAPU.1, U1.23 (SDA)
unnamed: R2.1, SCLPU.2
unnamed: R1.1, SDAPU.2
RESET: JP3.5, R6.1, U1.3 (#RESET)
VCC: A0.2, A1.2, A2.1, C1.1, JP3.1, R1.2, R2.2, R6.2, U1.24 (VCC)

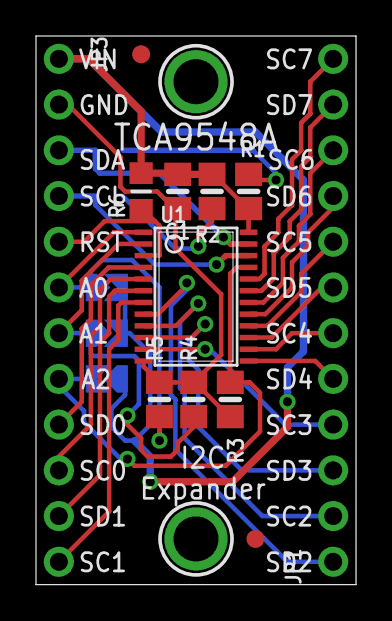
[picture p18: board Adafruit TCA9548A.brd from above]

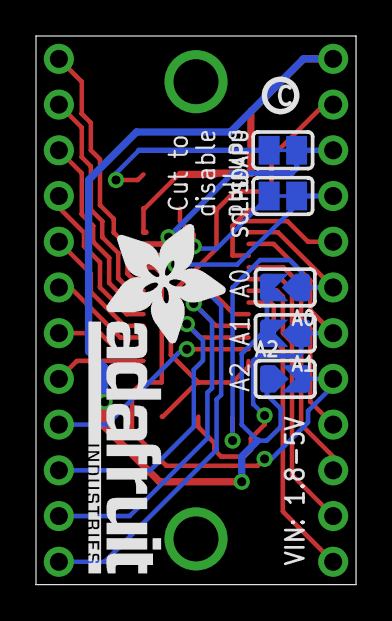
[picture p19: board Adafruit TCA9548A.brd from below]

Board: 2 copper layers, 17.8 x 30.5 mm, 21 parts (7 on the bottom side), 26 nets.

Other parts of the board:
U$6: PCBFEAT-REV-040
U$7: ADAFRUIT_TEXT_20MM

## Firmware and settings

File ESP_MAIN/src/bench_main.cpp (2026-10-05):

#include <Arduino.h>
#include <cstdio>
#include <cstring>

#include "app/boot_manager.hpp"
#include "bench/bench_config.hpp"
#include "bench/bench_controller.hpp"
#include "communication/raspberry_link.hpp"
#include "motor/motor_controller.hpp"
#include "sensors/color_sensor_manager.hpp"
#include "sensors/sensor_manager.hpp"
#include "system/event_logger.hpp"
#include "system/status_led.hpp"
#include "system/system_manager.hpp"

namespace {
using namespace config::bench;
char input[48];
uint8_t inputLength = 0;
bool discardLine = false, logging = false;
uint32_t lastInputMs = 0, lastLogMs = 0;
uint8_t logRow = 5;

void stop() {
  SystemManager::requestStop();
  MotorController::brake();
  BenchController::select(BenchController::mode());
}

void help() {
  Serial.println("MODE STOP|MOTOR|MANUAL|DATA|ALIGN|FOLLOW|AVOID");
  Serial.println("Select mode, then press/release SW2 to arm motion.");
  Serial.printf("DRIVE <left> <right>: %d..%d, repeat <%lums in MANUAL.\n",
                -OUTPUT_LIMIT, OUTPUT_LIMIT, static_cast<unsigned long>(MANUAL_HOLD_MS));
  Serial.println("STOP / LOG ON / LOG OFF / STATUS / HELP; UART0 57600, newline.");
}

void execute(const char* line) {
  if (!strcmp(line, "STOP")) { stop(); Serial.println("OK STOP"); return; }
  if (!strcmp(line, "HELP")) { stop(); help(); return; }
  if (!strcmp(line, "LOG ON")) { logging = true; return; }
  if (!strcmp(line, "LOG OFF")) { logging = false; logRow = 5; return; }
  if (!strcmp(line, "STATUS")) { logging = true; lastLogMs = millis() - LOG_PERIOD_MS; return; }
  if (!strncmp(line, "MODE ", 5)) {
    for (uint8_t i = 0; i <= static_cast<uint8_t>(BenchMode::Avoid); ++i) {
      const auto mode = static_cast<BenchMode>(i);
      if (strcmp(line + 5, BenchController::modeName(mode))) continue;
      stop(); BenchController::select(mode);
      if (mode == BenchMode::Data) logging = true;
      EventLogger::modeChanged(i);
      Serial.printf("OK MODE %s; SW2 required for motion\n", BenchController::modeName(mode));
      return;
    }
  }
  if (!strncmp(line, "DRIVE ", 6)) {
    // Bound input before scanf: overflowing integer strings are rejected.
    size_t position = 6;
    int values[2] = {};
    bool valid = true;
    for (int axis = 0; axis < 2; ++axis) {
      while (line[position] == ' ') ++position;
      const bool negative = line[position] == '-';
      if (negative || line[position] == '+') ++position;
      uint8_t digits = 0;
      while (line[position] >= '0' && line[position] <= '9') {
        if (++digits > 3) { valid = false; break; }
        values[axis] = values[axis] * 10 + line[position++] - '0';
      }
      if (!digits || !valid) { valid = false; break; }
      if (negative) values[axis] = -values[axis];
      if (axis == 0 && line[position] != ' ') { valid = false; break; }
    }
    while (line[position] == ' ') ++position;
    if (valid && line[position] == '\0' &&
        BenchController::setManual(values[0], values[1], millis(), SystemManager::motorAllowed())) {
      return;  // Avoid acknowledgements on a fast manual command stream.
    }
  }
  stop(); Serial.println("ERR command rejected; stopped");
}

void console() {
  if (inputLength && millis() - lastInputMs >= CONSOLE_TIMEOUT_MS) {
    stop(); inputLength = 0; discardLine = true;
  }
  uint8_t budget = CONSOLE_BYTES_PER_LOOP;
  while (budget-- && Serial.available()) {
    const char c = static_cast<char>(Serial.read());
    lastInputMs = millis();
    if (c == '\r' || c == '\n') {
      if (!discardLine && inputLength) { input[inputLength] = 0; execute(input); }
      inputLength = 0; discardLine = false;
    } else if (!discardLine) {
      if (static_cast<size_t>(inputLength) + 1 >= sizeof(input) || c < 32 || c > 126) {
        stop(); inputLength = 0; discardLine = true;
      } else input[inputLength++] = c;
    }
  }
}

void telemetry(uint32_t now) {
  if (!logging) return;
  if (logRow >= 5) {
    if (now - lastLogMs < LOG_PERIOD_MS) return;
    lastLogMs = now; logRow = 0;
  }
  if (now - lastLogMs >= LOG_FRAME_TIMEOUT_MS) { logRow = 5; return; }
  char line[128];
  int length = 0;
  const auto sensors = SensorManager::snapshot();
  if (logRow == 0) {
    const auto vision = RaspberryLink::latest();
    const auto motor = MotorController::status();
    length = snprintf(line, sizeof(line), "D,%lu,%s,%u,%d,%d,%u,%u,%u,%u,%u,%u\r\n",
        static_cast<unsigned long>(now), BenchController::modeName(BenchController::mode()),
        SystemManager::motorAllowed() ? 1 : 0, motor.appliedLeftPermille,
        motor.appliedRightPermille, vision.linkValid ? 1 : 0, vision.frameFresh ? 1 : 0,
        vision.targetValid ? 1 : 0, vision.targetX, vision.targetHeight,
        BenchController::hazardMask(sensors));
  } else {
    const uint8_t i = logRow - 1;
    const auto& raw = sensors.colorRaw[i];
    const auto& floor = sensors.floorColor[i];
    const bool as = ColorSensorManager::model() == ColorSensorModel::AS7341;
    length = snprintf(line, sizeof(line), "S,%lu,%u,%lu,%u,%s,%u,%u,%u,%u,%u,%u,%u,%u\r\n",
        static_cast<unsigned long>(now), static_cast<unsigned>(i + 1),
        static_cast<unsigned long>(raw.sequence), raw.valid ? 1 : 0,
        floorColorName(floor.color), floor.reliable ? 1 : 0, raw.brightness,
        raw.channel[as ? 1 : 0], raw.channel[as ? 2 : 1], raw.channel[as ? 4 : 2],
        raw.channel[as ? 5 : 8], raw.channel[as ? 6 : 8],
        static_cast<unsigned>(ColorSensorManager::status().error[i]));
  }
  // Telemetry is best-effort; never wait for UART space while driving.
  if (length > 0 && static_cast<size_t>(length) < sizeof(line) && Serial.availableForWrite() >= length) {
    Serial.write(reinterpret_cast<const uint8_t*>(line), length);
    ++logRow;
  }
}
}

void setup() {
  const auto boot = BootManager::begin();
  if (!boot.safeToRun) {
    while (true) { BootManager::staySafe(); StatusLed::update(millis()); delay(10); }
  }
  MotorController::setOutputLimit(OUTPUT_LIMIT);
  BenchController::begin();
  inputLength = 0; discardLine = logging = false; logRow = 5;
  lastInputMs = lastLogMs = millis();
  help();
}

void loop() {
  SystemManager::update(millis());
  RaspberryLink::poll();
  SensorManager::update();
  SystemManager::update(millis());
  console();
  const auto command = BenchController::update(millis(), SystemManager::motorAllowed(),
      SensorManager::snapshot(), RaspberryLink::latest());
  if (SystemManager::motorAllowed()) {
    if (!MotorController::apply(command, SystemManager::safetyStatus()) &&
        MotorController::status().lastResult == MotorControlResult::DriverFailure)
      SystemManager::setMotorHealthy(false, FaultCode::Driver);
  } else MotorController::brake();
  if (BenchController::finished()) { stop(); Serial.println("DONE MOTOR"); }
  StatusLed::update(millis());
  EventLogger::process();
  telemetry(millis());
  delay(1);
}

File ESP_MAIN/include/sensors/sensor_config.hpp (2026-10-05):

#pragma once

#include <Arduino.h>

namespace config {
namespace sensors {

// Change only this line when building for the other color sensor board.
#define COLOR_SENSOR_AS7341 1
#define COLOR_SENSOR_TCS34725 2
#ifndef COLOR_SENSOR_MODEL
#define COLOR_SENSOR_MODEL COLOR_SENSOR_AS7341
#endif

// These are safe starting values. Final timing must be measured on the robot.
constexpr uint32_t COLOR_SENSOR_SLOT_PERIOD_MS = 1;
constexpr uint8_t COLOR_SENSOR_VISITS_PER_UPDATE =
    COLOR_SENSOR_MODEL == COLOR_SENSOR_AS7341 ? 4 : 1;

constexpr uint8_t TCA9548A_ADDRESS = 0x70;
constexpr uint32_t I2C_FREQUENCY_HZ = 400000;
constexpr uint16_t I2C_TIMEOUT_MS = 5;
constexpr uint32_t CONVERSION_TIMEOUT_MARGIN_MS = 100;
constexpr uint32_t SMUX_TIMEOUT_MS = 30;
constexpr uint8_t COLOR_SENSOR_COUNT = 4;

// Robot front is up: 1=front-left, 2=front-right,
// 3=rear-left, 4=rear-right.
constexpr uint8_t COLOR_SENSOR_TCA_CHANNELS[COLOR_SENSOR_COUNT] = {0, 1, 2, 3};

// ---------------------------------------------------------------------------
// Color sensor exposure settings. Change these values in this file only.
// ---------------------------------------------------------------------------
enum class As7341Gain : uint8_t {
  X0_5,
  X1,
  X2,
  X4,
  X8,
  X16,
  X32,
  X64,
  X128,
  X256,
  X512,
};

enum class Tcs34725Gain : uint8_t {
  X1,
  X4,
  X16,
  X60,
};

enum class Tcs34725Integration : uint8_t {
  Ms2_4 = 0xFF,
  Ms24 = 0xF6,
  Ms50 = 0xEB,
  Ms101 = 0xD6,
  Ms154 = 0xC0,
  Ms614 = 0x00,
};

// AS7341 integration time is approximately
// (ATIME + 1) * (ASTEP + 1) * 2.78 us.
constexpr uint32_t AS7341_EXPOSURE_US = 5000;  // Edit this, not ATIME/ASTEP.
constexpr uint8_t AS7341_INTEGRATION_ATIME = 0;
constexpr uint16_t AS7341_INTEGRATION_ASTEP =
    (AS7341_EXPOSURE_US * 100UL) / 278UL - 1UL;
constexpr As7341Gain AS7341_GAIN = As7341Gain::X16;
// Applies only to modules with white LED wired to AS7341 LDR.
constexpr bool AS7341_LED_ENABLED = true;
constexpr uint16_t AS7341_LED_CURRENT_MA[COLOR_SENSOR_COUNT] = {20, 20, 20, 20};
constexpr uint8_t AS7341_AUTOZERO_INTERVAL = 255;  // Before first sample only.
constexpr uint16_t MINIMUM_CLEAR_COUNTS = 1;
static_assert(AS7341_EXPOSURE_US >= 6 && AS7341_EXPOSURE_US <= 182000,
              "Invalid AS7341 exposure");
static_assert(COLOR_SENSOR_VISITS_PER_UPDATE >= 1 &&
              COLOR_SENSOR_VISITS_PER_UPDATE <= COLOR_SENSOR_COUNT,
              "Invalid scan count");

constexpr Tcs34725Integration TCS34725_INTEGRATION =
    Tcs34725Integration::Ms2_4;
constexpr Tcs34725Gain TCS34725_GAIN = Tcs34725Gain::X16;

// A color becomes reliable only after this many consecutive identical reads.
constexpr uint8_t COLOR_CONFIRM_COUNT = 3;
static_assert(COLOR_CONFIRM_COUNT >= 3, "At least three color samples required");

constexpr uint32_t AS7341_INTEGRATION_MS =
    ((AS7341_INTEGRATION_ATIME + 1ULL) * (AS7341_INTEGRATION_ASTEP + 1ULL) *
         278ULL + 99999ULL) / 100000ULL;
constexpr uint32_t TCS34725_INTEGRATION_MS =
    ((256UL - static_cast<uint8_t>(TCS34725_INTEGRATION)) * 24UL + 9UL) / 10UL;
constexpr uint32_t SAMPLE_STALE_MS =
    (COLOR_SENSOR_MODEL == COLOR_SENSOR_AS7341
         ? AS7341_INTEGRATION_MS
         : TCS34725_INTEGRATION_MS) + 250;
static_assert(AS7341_INTEGRATION_ASTEP < 65535, "ASTEP 65535 is reserved");
static_assert(AS7341_INTEGRATION_ATIME != 0 || AS7341_INTEGRATION_ASTEP != 0,
              "AS7341 ATIME and ASTEP cannot both be zero");
static_assert(TCA9548A_ADDRESS >= 0x70 && TCA9548A_ADDRESS <= 0x77,
              "Invalid TCA9548A address");

// Fallback thresholds used when no NVS calibration exists. These are only
// starting values and must be adjusted with real floor measurements.
constexpr uint16_t FALLBACK_AS7341_BLACK_CLEAR_BY_SENSOR[COLOR_SENSOR_COUNT] =
    {180, 180, 180, 180};
constexpr uint16_t FALLBACK_TCS34725_BLACK_CLEAR_BY_SENSOR[COLOR_SENSOR_COUNT] =
    {120, 120, 120, 120};
constexpr float FALLBACK_RED_DOMINANCE = 1.20f;
constexpr float FALLBACK_BLUE_DOMINANCE = 1.18f;
constexpr float FALLBACK_YELLOW_OVER_BLUE = 1.30f;
constexpr float FALLBACK_YELLOW_RG_MIN = 0.55f;
constexpr float FALLBACK_YELLOW_RG_MAX = 1.80f;
constexpr float MATCH_MINIMUM_SCALE = 0.005f;
constexpr float MATCH_MAXIMUM_SCORE = 1.0f;
constexpr float MATCH_MINIMUM_WINNER_GAP = 0.08f;
constexpr float MATCH_COLOR_BRIGHTNESS_WEIGHT = 0.20f;
constexpr float MATCH_BLACK_BRIGHTNESS_WEIGHT = 0.55f;
static_assert(MATCH_COLOR_BRIGHTNESS_WEIGHT >= 0 && MATCH_COLOR_BRIGHTNESS_WEIGHT <= 1 &&
              MATCH_BLACK_BRIGHTNESS_WEIGHT >= 0 && MATCH_BLACK_BRIGHTNESS_WEIGHT <= 1,
              "Invalid brightness weights");
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

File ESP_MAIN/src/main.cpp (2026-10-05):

#include <Arduino.h>

#include "app/boot_manager.hpp"
#include "communication/raspberry_link.hpp"
#include "control/drive_logic.hpp"
#include "control/robot_fsm.hpp"
#include "interrupts/button_interrupts.hpp"
#include "motor/motor_controller.hpp"
#include "sensors/color_calibration.hpp"
#include "sensors/sensor_manager.hpp"
#include "system/event_logger.hpp"
#include "system/status_led.hpp"
#include "system/system_manager.hpp"

namespace {

[[noreturn]] void stayInBootFailure() {
  while (true) {
    BootManager::staySafe();
    StatusLed::update(millis());
    delay(10);
  }
}

void showRobotState(RobotState state) {
  static RobotState previous = RobotState::Boot;
  if (state == previous) return;
  previous = state;
  StatusLed::clear(LedOwner::Fsm);
  switch (state) {
    case RobotState::Search:
      StatusLed::setBoth(LedOwner::Fsm, LedState::Searching);
      break;
    case RobotState::TargetConfirm:
      StatusLed::setBoth(LedOwner::Fsm, LedState::Tracking);
      break;
    case RobotState::TrackAlign:
      StatusLed::setBoth(LedOwner::Fsm, LedState::Aligning);
      break;
    case RobotState::Approach:
      StatusLed::setBoth(LedOwner::Fsm, LedState::Approaching);
      break;
    case RobotState::DiveReady:
      StatusLed::setBoth(LedOwner::Fsm, LedState::Charging);
      break;
    case RobotState::DiveBrake:
    case RobotState::SpokeEngaged:
    case RobotState::Push:
      StatusLed::setBoth(LedOwner::Fsm, LedState::Pushing);
      break;
    case RobotState::Backoff:
    case RobotState::ZoneEscape:
      StatusLed::setBoth(LedOwner::Fsm, LedState::ZoneEscape);
      break;
    case RobotState::LostTarget:
      StatusLed::setBoth(LedOwner::Fsm, LedState::CommunicationLost);
      break;
    default:
      break;
  }
}

}  // namespace

void setup() {
  const BootResult boot = BootManager::begin();
  if (!boot.safeToRun) stayInBootFailure();

  RobotFsm::begin();
  EventLogger::logText(static_cast<uint16_t>(EventId::Custom),
                       LogSeverity::Info, LogSource::System,
                       "fsm_ready");
}

void loop() {
  uint32_t nowMs = millis();
  const bool calibrationWasActive = ColorCalibration::active();

  // Safety comes first; each sensor step only performs short I2C transfers.
  SystemManager::update(nowMs);
  if (calibrationWasActive && ButtonInterrupts::startPressed()) {
    ButtonInterrupts::cancelStartGesture();
  }

  RaspberryLink::poll();
  SensorManager::update();
  nowMs = millis();
  SystemManager::update(nowMs);
  if (calibrationWasActive && ButtonInterrupts::startPressed()) {
    ButtonInterrupts::cancelStartGesture();
  }

  SystemStatus system = SystemManager::status();
  const bool calibrationAllowed =
      (system.state == SystemState::WaitingForStart ||
       system.state == SystemState::Calibration) &&
      !ButtonInterrupts::startPressed();
  ColorCalibration::update(nowMs, calibrationAllowed);

  const bool calibrationActive = ColorCalibration::active();
  SystemManager::setCalibrationActive(calibrationActive);
  if (calibrationWasActive && !calibrationActive) {
    SystemManager::requestStop();
  }
  system = SystemManager::status();

  if (calibrationActive || calibrationWasActive) {
    MotorController::brake();
    StatusLed::update(nowMs);
    EventLogger::process();
    delay(1);
    return;
  }

  nowMs = millis();

  const SensorSnapshot sensors = SensorManager::snapshot();
  const VisionSnapshot vision = RaspberryLink::latest();
  const DriveIntent driveIntent =
      RobotFsm::update(nowMs, sensors, vision, system.safety);
  const MotorCommand command = DriveLogic::makeCommand(nowMs, driveIntent);

  if (system.motorAllowed) {
    if (!MotorController::apply(command, system.safety) &&
        MotorController::status().lastResult == MotorControlResult::DriverFailure) {
      SystemManager::setMotorHealthy(false, FaultCode::Driver);
    }
  } else {
    MotorController::brake();
  }

  showRobotState(RobotFsm::state());
  StatusLed::update(nowMs);
  EventLogger::process();
  delay(1);  // Yield to the watchdog and ESP32 background tasks.
}

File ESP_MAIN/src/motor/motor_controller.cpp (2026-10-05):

#include "motor/motor_controller.hpp"

#include <freertos/FreeRTOS.h>
#include <freertos/semphr.h>
#include <freertos/task.h>

#include "motor/bts7960_driver.hpp"
#include "motor/motor_config.hpp"
#include "pins.hpp"

namespace {
Bts7960Driver leftMotor({pins::MOTOR1_LPWM, pins::MOTOR1_RPWM,
                         pins::MOTOR1_LEN, pins::MOTOR1_REN,
                         config::motor::MOTOR1_LPWM_CHANNEL,
                         config::motor::MOTOR1_RPWM_CHANNEL});
Bts7960Driver rightMotor({pins::MOTOR2_LPWM, pins::MOTOR2_RPWM,
                          pins::MOTOR2_LEN, pins::MOTOR2_REN,
                          config::motor::MOTOR2_LPWM_CHANNEL,
                          config::motor::MOTOR2_RPWM_CHANNEL});

StaticSemaphore_t motorMutexStorage;
SemaphoreHandle_t motorMutex = nullptr;
MotorControllerStatus latestStatus;
StaticTask_t watchdogTaskStorage;
StackType_t watchdogStack[2048 / sizeof(StackType_t)];
TaskHandle_t watchdogTask = nullptr;

void motorWatchdog(void*) {
  for (;;) {
    vTaskDelay(pdMS_TO_TICKS(config::motor::WATCHDOG_POLL_MS));
    MotorController::checkTimeout(millis());
  }
}

class MotorLock {
 public:
  MotorLock() {
    if (motorMutex != nullptr) {
      locked_ = xSemaphoreTake(motorMutex, portMAX_DELAY) == pdTRUE;
    }
  }

  ~MotorLock() {
    if (locked_) {
      xSemaphoreGive(motorMutex);
    }
  }

 private:
  bool locked_ = false;
};

bool deadlinePassed(uint32_t nowMs, uint32_t deadlineMs) {
  return static_cast<int32_t>(nowMs - deadlineMs) >= 0;
}

int16_t clampCommand(int32_t value) {
  return static_cast<int16_t>(constrain(
      value, -config::motor::COMMAND_MAX, config::motor::COMMAND_MAX));
}

int16_t applyLimit(int16_t value, int16_t limit) {
  return static_cast<int16_t>(constrain(value, -limit, limit));
}

int16_t positiveMagnitude(int16_t value) {
  int32_t magnitude = value;
  if (magnitude < 0) {
    magnitude = -magnitude;
  }
  return clampCommand(magnitude);
}

void refreshDriverStatus() {
  latestStatus.leftDriver = leftMotor.status();
  latestStatus.rightDriver = rightMotor.status();
  latestStatus.outputsActive =
      latestStatus.leftDriver.appliedPermille != 0 ||
      latestStatus.rightDriver.appliedPermille != 0;
}

void stopLocked(StopMode mode) {
  leftMotor.stop(mode);
  rightMotor.stop(mode);
  latestStatus.stopMode = mode;
  latestStatus.appliedLeftPermille = 0;
  latestStatus.appliedRightPermille = 0;
  latestStatus.commandValidUntilMs = 0;
  refreshDriverStatus();
}

void rejectLocked(MotorControlResult result, StopMode mode) {
  stopLocked(mode);
  latestStatus.lastResult = result;
  ++latestStatus.rejectedCommandCount;
}
}

bool MotorController::begin() {
  if (motorMutex == nullptr) {
    motorMutex = xSemaphoreCreateMutexStatic(&motorMutexStorage);
  }
  if (motorMutex == nullptr) {
    latestStatus = MotorControllerStatus{};
    latestStatus.lastResult = MotorControlResult::NotInitialized;
    Bts7960Driver::initializeDriveInhibit();
    return false;
  }
  MotorLock lock;

  latestStatus = MotorControllerStatus{};
  latestStatus.outputLimitPermille = config::motor::DEFAULT_OUTPUT_LIMIT;
  latestStatus.emergencyStopLatched = true;
  Bts7960Driver::initializeDriveInhibit();

  const bool leftReady = leftMotor.begin();
  const bool rightReady = rightMotor.begin();
  latestStatus.initialized = leftReady && rightReady;
  stopLocked(StopMode::Brake);
  latestStatus.lastResult = latestStatus.initialized
                                ? MotorControlResult::EmergencyStopLatched
                                : MotorControlResult::DriverFailure;
  if (latestStatus.initialized && watchdogTask == nullptr) {
    // ESP-IDF task stack size is in bytes. This task only checks motor expiry.
    watchdogTask = xTaskCreateStatic(motorWatchdog, "motor_watchdog",
                                    sizeof(watchdogStack), nullptr, 2,
                                    watchdogStack, &watchdogTaskStorage);
    if (watchdogTask == nullptr) {
      latestStatus.initialized = false;
      latestStatus.lastResult = MotorControlResult::NotInitialized;
    }
  }
  return latestStatus.initialized;
}

bool MotorController::apply(const MotorCommand& command,
                            const SafetyStatus& safety) {
  MotorLock lock;
  const uint32_t nowMs = millis();
  const uint32_t effectiveDeadline =
      !command.deadlineSet && command.validUntilMs == 0
          ? nowMs + config::motor::DEFAULT_COMMAND_TIMEOUT_MS
          : command.validUntilMs;
  latestStatus.requestedLeftPermille = command.leftPermille;
  latestStatus.requestedRightPermille = command.rightPermille;
  latestStatus.lastCommandMs = nowMs;
  latestStatus.commandValidUntilMs = effectiveDeadline;
  latestStatus.lastSafetyState = safety.state;

  if (!latestStatus.initialized) {
    rejectLocked(MotorControlResult::NotInitialized, StopMode::Brake);
    return false;
  }
  if (latestStatus.emergencyStopLatched) {
    rejectLocked(MotorControlResult::EmergencyStopLatched, StopMode::Brake);
    return false;
  }
  if (!safety.motorAllowed || safety.state != SafetyState::Running) {
    rejectLocked(MotorControlResult::SafetyBlocked, StopMode::Brake);
    return false;
  }
  if (deadlinePassed(nowMs, effectiveDeadline)) {
    rejectLocked(MotorControlResult::CommandExpired, StopMode::Brake);
    return false;
  }

  const int16_t left = applyLimit(
      clampCommand(command.leftPermille), latestStatus.outputLimitPermille);
  const int16_t right = applyLimit(
      clampCommand(command.rightPermille), latestStatus.outputLimitPermille);

  if (left == 0 && right == 0) {
    stopLocked(command.stopMode);
    latestStatus.lastResult = MotorControlResult::Accepted;
    ++latestStatus.acceptedCommandCount;
    return true;
  }

  const int16_t physicalLeft =
      config::motor::LEFT_MOTOR_INVERTED ? -left : left;
  const int16_t physicalRight =
      config::motor::RIGHT_MOTOR_INVERTED ? -right : right;
  bool leftOk = true;
  bool rightOk = true;
  if (physicalLeft == 0) {
    leftMotor.stop(command.stopMode);
  } else {
    leftOk = leftMotor.drive(physicalLeft);
  }
  if (physicalRight == 0) {
    rightMotor.stop(command.stopMode);
  } else {
    rightOk = rightMotor.drive(physicalRight);
  }
  refreshDriverStatus();

  if (!leftOk || !rightOk) {
    rejectLocked(MotorControlResult::DriverFailure, StopMode::Brake);
    return false;
  }

  // Controller-level applied values stay in logical robot coordinates. The
  // nested driver values expose the physical values after inversion.
  latestStatus.appliedLeftPermille = left;
  latestStatus.appliedRightPermille = right;
  latestStatus.stopMode = command.stopMode;
  latestStatus.lastResult = MotorControlResult::Accepted;
  ++latestStatus.acceptedCommandCount;
  return true;
}
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

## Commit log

2026-10-03 Add robot project source and hardware files
    [Adafruit TCA9548A.brd, Adafruit TCA9548A.sch, C_ROBOT.kicad_pcb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]
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2026-10-05 Save remaining PCB V2, vision tools, backups and preview assets
    [Adafruit TCA9548A.brd, Adafruit TCA9548A.sch, C_ROBOT.kicad_pcb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]
2026-10-05 Optimize continuous AS7341 floor sensing and document variable clearance
    [color_calibration.cpp, color_sensor_manager.cpp, fake_hardware.cpp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]
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2026-10-05 Fix stop rearming and live hazard handling; validate calibration inputs
    [bench_controller.cpp, button_interrupts.cpp, color_calibration.cpp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]
2026-10-10 Add robot mechanical models and CG simulator
    [C_ROBOT_PCB_3D.step, F608ZZ.step]
2026-10-10 Document final chassis and belt drive decisions
    [belt_260_corrected_18.249x36.dxf, belt_260_pitchline_check.dxf, belt_requested_13x36_263.23mm.dxf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]
2026-10-14 Add firmware map and header contracts to cut AI reading cost
    - Add ESP_MAIN/MAP.md: per-task file guide, source-of-truth table for
    pins and config values, loop() order, module table, add/remove steps.
    - Add a short "Contract" comment above each module class in 16 headers
    (role, caller, failure behavior, safety flag). Comments only.
    - Reduce ESP_MAIN/AGENTS.md to rules; pin, LED, packet and API tables now
    point to pins.hpp, headers and README instead of duplicating them.
    - Root AGENTS.md: required reading is now MAP.md, ESP_MAIN/AGENTS.md and
    the target header contract; README/VERIFICATION/BENCH_TESTS on demand.
    Host tests: AS7341 4994 and TCS34725 4555 checks passed.
    Build: pio run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
2026-10-14 Split color calibration into its own firmware; add groove exit to FSM
    Calibration
    - Add CalibrationStore (NVS load/validate/save/erase). Production and
    bench firmware only load stored values at boot; NVS format unchanged.
    - Move the 48-step console to src/calibration/ with a new entry point
    src/calibration_main.cpp and PlatformIO envs color_calibration and
    color_calibration_tcs34725. It never initializes the motors and keeps
    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
2026-10-14 Add field teammate guide for AI-assisted firmware work
    - Add ESP_MAIN/TEAM_GUIDE.md for a non-coding teammate on site: robot
    overview, the four upload targets, where to change what, how the loop,
    safety paths and FSM behave, LED meanings, intended designs that must
    not be "fixed", known limits and unverified items, tuning table, AI
    prompts to use and refuse, first field steps, troubleshooting and log
    number table.
    - Link it from MAP.md and the root AGENTS.md reading list, with a rule to
    explain each change in plain words and get consent before editing.
2026-10-23 Add V2 board support behind HW_VERSION=2 (v2 branch only)
    V2 pin map in pins_v2.hpp, selected only by the *_v2 PlatformIO
    environments; V1 pins and the default build are unchanged. SW1 ISR EN
    masks are now computed from pins.hpp (same V1 pins), the external LED is
    skipped on V2, and host tests gain a -V2 switch. Builds: all four V2
    environments and V1 production. Host tests: V1 and V2 pass.
    Not yet run on an assembled V2 board.
2026-10-23 Add power-on battery check for the V2 board
    BatteryMonitor reads the x11 battery divider for up to 3 s after boot.
    The pack must stay within CELL_COUNT x [3.3 V, 4.25 V] (default 4S) for
    five samples in a row; otherwise the battery is reported as missing, low
    or too high and SystemManager::setApplicationHealthy(false) blocks start
    until reboot. V1 skips the check. Host tests cover OK, missing, 3S, 5S
    and a late-connected pack on V2; V1 and V2 builds pass.
    Divider and ADC accuracy are not yet verified on the V2 board.
2026-10-25 Accept 3S and 4S packs; add bench battery line and PC console
    - Power-on battery check now accepts any pack that fits 3S or 4S per-cell
    limits (consecutive samples must agree on the cell count) and reports the
    detected cell count.
    - robot_bench prints one "BAT <result> <mV> <cells>S" line after the check,
    so the V2 divider can be compared with a multimeter.
    - tools/bench_console.py: sends whole lines and repeats DRIVE every 100 ms,
    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
2026-10-31 V2 bench: IMU check, calibration inside the bench, GUI, retire unused envs
    Builds on qkssla's robot_bench_v2_manual (420462af).
    - Bench cleanup: drop pio.cmd; keep every telemetry line under the 128-byte
    UART0 FIFO (diagnostics become their own rotating rows); restore the mode
    name in the MODE reply.
    - ImuMonitor (V2, MPU6050): reset, WHO_AM_I, data-ready/freshness check,
    one short I2C transaction per update, Fault without auto-retry. Bench
    prints an I row and accepts IMU RESET.
    - Floor color calibration now runs inside the bench firmware: CAL START
    routes every console line to ColorCalibration, motors are braked each loop,
    telemetry pauses, and a CAL status line is printed ever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
2026-10-31 Review fixes: test SW2 hold during battery check, GUI saturation at AS7341 full scale
    - Host test: SW2 pressed while the battery is being judged is dropped and a
    new press is needed after Ok (covers the merged SystemManager::holdStart).
    - bench_gui: saturation warning and preview bar use the AS7341 5 ms full
    scale (1798) instead of 65535; NOT_READY preview hints at saturation.
    - BENCH_TESTS/VERIFICATION: 3 mm saturation note and review record.
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2026-11-01 Bench: pin state row and GUI panel, one-click drive ready, IMU diagnostics
    - PIN telemetry row: SW1/SW2, EN1/EN2 levels and the four LEDC duties read
    back from the board every 0.6 s; GUI shows them as an 8-tile pin panel.
    - GUI: "drive ready" button sends MODE MANUAL then software SW2; releasing a
    direction key only stops the DRIVE repeat (board stops within 250 ms) so
    permission stays; STOP still clears it. Power slider starts at 200.
    - IMU: I row adds why data is not fresh (no data / frozen) and PWR_MGMT_1
    read back every 0.5 s (0x40 = chip reset itself and sleeps). No auto re-init.
    Host tests (bench 380+4, default 5020/4581, V2 5041), GUI self-check and both
    V2 builds pass. Not r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
2026-11-01 V2: invert both motors; bench shows every pin (IS, IR, BAT, SDA/SCL)
    - motor_config: on V2 positive output drove both wheels backward on the
    11/01 lifted-wheel test, so LEFT/RIGHT_MOTOR_INVERTED = true for
    HW_VERSION 2 only. V1 stays false.
    - Bench ADC row: all 11 analog pins (4 IS, 6 IR, battery pin) in mV at the
    GPIO, one conversion per loop. PIN row adds SDA/SCL levels.
    - GUI pin panel shows 21 tiles with GPIO numbers.
    Host tests (default 5020/4581, V2 5041, bench 432+4), GUI self-check and
    V2 builds (match, bench, raw_motor) pass. Direction change not yet
    confirmed on the robot.
2026-11-01 Bench: I2C SCAN command and GUI button (mux presence, devices per channel)
    New bench_v2/i2c_scan module: finds a TCA9548A at 0x70..0x77, scans the
    main bus with every channel off, then each mux channel; eight address
    probes per loop, mux state set again each step, all channels off at the
    end. Three bus errors in a row abort with I2C ERR BUS. Motors are stopped
    when a scan starts. GUI pin panel gets an "I2C 스캔" button and a one-line
    summary. Host fakes now ACK address-only probes per real address.
    Host tests (default 5020/4581, V2 5041, bench 441+4), GUI self-check and
    V2 builds pass. Not run on the real board.
2026-11-03 V2: drop motor inversion again after the 11/04 rewiring
    With both motors inverted, both wheels ran backward on the rebuilt board, so
    LEFT/RIGHT_MOTOR_INVERTED go back to false for V2. Bench PIN test and notes follow.
2026-11-04 Buttons need a 0.5 s hold, 12-step calibration, Pi vision sender
    On the robot, slamming down pressed SW1/SW2 by itself, so every button
    now acts only after being held 0.5 s (config::switches::HOLD_MS). The SW1
    ISR only marks edges; the main loop and the motor watchdog task check the
    hold, so a stalled loop cannot delay the stop. While running, a held SW2
    is an emergency stop too. Boot with SW1 held still latches at once.
    Color calibration drops yellow and measures several corners at once:
    black/red/blue x (level all 4, lifted all 4, pressed front pair, pressed
    rear pair) = 12 steps, 1 s countdown and 1 s measurement. NVS format is
    unchanged; the store skips yellow. Yellow is no longer a haz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
2026-11-04 Bench: flash the ESP32 from the Raspberry Pi for remote work
    Build on a PC, copy the four .bin files to the Pi, and write them with
    upstream esptool over the CH343 USB port (/dev/ttyACM0). Debian's esptool
    package lacks the flasher stub, so the Pi uses esptool 4.8.1 from pip.
    Tested 11/04: flash from the Pi, hash verified, board rebooted and kept
    receiving the Pi vision packets.
2026-11-04 Bench: SW2 3 s tower align, faster camera, Wi-Fi auto-restore, cal message fix
    - Bench firmware: SW2 held 3 s while stopped selects ALIGN; the release starts it.
    ALIGN only spins in place, ±200 px center window, output ramps 250 -> 350
    with distance from center, and after losing the tower it spins toward the
    side last seen for about 3 s. Spin trims (default 0) for a weaker side.
    - Turn output 120 -> 300 (below ~250 the robot does not turn).
    - Pi sender: 1280x720 (search 640x360), ~45 fps and ~33 ms frame age
    instead of ~33 fps / ~83 ms at 1920x1080.
    - Pi: back up and restore Wi-Fi profiles that a power cut empties
    (pi_netfix.py + two systemd units, tests).
    - Bench GUI: "Too few sa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
2026-11-04 Pi vision: HSV tower detector with live calibrator, desktop launchers
    - scripts/tower_detector_hsv.py: small-frame HSV proposal, full-frame HSV check,
    then pick the tower (not flat, tracking among large blobs, size limits).
    Color range and size limits from config/tower_hsv.json, default = the range
    saved on 11/04 (H 51-67, S>=72, V>=32). On the 10/06 videos 84/93 vs 85/93
    for the old 4-filter detector; on the Pi worst case 50 ms -> 2.3 ms, 50 fps.
    - pi_vision_sender.py: --detector hsv (default) | legacy, --preview window.
    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
2026-11-05 Pi vision: tower settings app, multi-range colors, motion-blur camera defaults
    - scripts/tower_settings_app.py: live view with chosen/rejected blobs and the
    ALIGN window, color ranges (drag / shift+click widen / ctrl+click narrow,
    several ranges OR-ed), size and shape limits, camera controls, presets,
    snapshot / 10 s recording, Pi power status. Detection keeps running in its
    own thread (Pi: 50.5 fps, 4.3 ms with the window open).
    - tower_detector_hsv: several color ranges OR-ed so a tower split by shading
    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
2026-11-05 Pi: prefer caconee22 Wi-Fi, fall back to the open 307 network
    NetworkManager priorities pick caconee22 (10) over 307 (5) when connecting;
    a 30 s timer moves back to caconee22 once it is in range again (tested:
    on 307 at 18:29:39, back on caconee22 at 18:29:59).
2026-11-05 Battery check on/off switch in NVS, obeyed by the match firmware
    Bench 'BAT CHECK ON|OFF' (GUI button) saves the switch; both firmwares read
    it at power-on. Off: result Disabled, SW2 not held. Turning it off on the
    bench also lifts a failed check in the same boot (no auto start, a new SW2
    is needed); on applies from the next power-on. The check still only runs in
    the first 3 s, so a stall sag in a match never trips it. Verified on the
    board: failed check state 6 / fault 0x8 -> BAT CHECK OFF -> state 1 / 0x0.
    Also: bench GUI hides the Pi's ttyAMA*/ttyS* ports' hint text updated.
2026-11-05 Match FSM: fixes from the bench (spin floor, align ramp, lost-target side, contact hold)
    - Spin duties >= 300 / 280: below ~250 the robot did not spin in place and at
    260 one wheel stalled (TARGET_CONFIRM 240 -> 300).
    - Align: center window +-140 -> +-200 px and a ramp 280 -> 380 with the
    error (bench ALIGN swung left/right with one fixed duty).
    - Attack center +-75 -> +-150 px (inside the align window).
    - Lost tower: spin toward the last side 0.26 s -> 1.5 s, then search starts
    on that side.
    - A floor sensor blinded by contact (dark or saturated -> invalid sample) right
    after reading red/blue stays a hazard for HAZARD_CONTACT_HOLD_MS (300 ms,
    start value). Sensor classification is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
2026-11-08 Match firmware: wander, tilt e-stop, sensor retry, 710 limit, LED and cal spectrum
    - Pi unusable for 1 s -> Wander: random turn / forward-arc segments
    (repeated motion counts as a broken robot). Hazard escape still wins.
    - TiltGuard: IMU level learned while stopped; >80 deg for 3 s while
    running -> same permanent latch as SW1.
    - Floor sensor channel disabled by I2C/timeout/init gets at most 3
    re-inits, 1 s apart, split into power-on and configure steps (no wait).
    - Motor DEFAULT_OUTPUT_LIMIT 650 -> 710 so push 650 + steering 60 fits.
    - LED states cut to 10, bench GUI LED coach.
    - Calibration tab: per-channel spectrum bars for all 4 sensors.
    Host tests (V1/V2/bench) and both builds pas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
2026-11-08 Firmware review fixes: docs, single boot-fail log, drop unused helpers
    - Docs: SW1 0.5 s hold wording, sensor retry, IMU role, yellow is not a
    hazard, search vs wander behaviour.
    - BootManager::staySafe no longer re-logs BootFailed every loop.
    - Remove unused MotorController reverse/rotateLeft/rotateRight/coast and
    ButtonInterrupts::consumeEmergencyEvent/emergencyEventPending.
2026-11-08 README: bring every README up to the 11/08 state
    - Root: V2 board, the two firmwares, current status table, folder map,
    build/upload, Pi sender/services/icons, Pi-only config, tests,
    schedule page; old CV code and the 10/10 design kept as records.
    - ESP_MAIN: V2 hardware and pins, current environments, module table
    (battery, IMU, tilt guard, wander, bench v2), boot/loop order,
    calibration inside the bench firmware, LED table, bench-first test
    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
2026-11-09 Pi vision: skip zero-area blobs so min_area 0 cannot crash detection
    With min_area 0.0 saved from the tower settings app, a 1 px line passed the
    size check and cv2.moments gave m00 = 0, so the centroid divided by zero.
    The detect thread died: the camera view stayed black and c-robot-vision
    failed after 5 restarts (seen on the Pi 11/09). Such blobs are now skipped.
    Test reproduces the crash first. On the Pi: 9 detector tests pass, preview
    ran 30 s at 60 fps, 1412 packets, 0 dropped.
2026-11-09 Match FSM: lock-on escape, charge from farther, spin-only search
    11/09 first field run: driving and opponent finding were good, but the
    escape always turned away and dropped the target, the charge started only
    when very close, and the search swung left/right or wandered randomly.
    - Lock-on escape: a hazard on the front sensors only while tracking
    (align/approach/attack/push, tower seen within LOCKON_RECENT_MS) backs
    straight out without turning, keeps the target and pushes again. Rear
    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
2026-11-09 Schedule page: 11/9 status (first field run, FSM changes, camera view fix)
    Synced from the live page first so team edits are kept.
2026-11-09 Pi: tracking viewer that does not stop the sender
    Desktop icon "C_ROBOT 추적 화면" (scripts/vision_viewer.py) shows what the
    running c-robot-vision service sees. The sender hands every 4th small
    search frame and the boxes to /dev/shm (scripts/view_tap.py, a plain copy,
    no encoding) only while a viewer is alive; with no viewer it checks for the
    file once a second. Drawing and display run in the viewer at nice 10.
    Pi 11/10: detection stayed at 60 fps with the window open, viewer ~15 fps.
2026-11-09 Match FSM rebuilt step by step: opening move, align, charge, floor escape; motor trim
    The 11/09 FSM changes made it hard to tell which part caused the jitter on
    the field, so the match firmware now runs a new small FSM (AlignFsm,
    ALIGN_ONLY_FSM=true; RobotFsm kept and selectable). Priority per pass:
    safety > floor escape > opening move > charge > align > search.
    - opening_move: fixed routine after each SW2 start (left 45, 2 s forward,
    left 90), time based, tuned on the field 11/10; duty x1.167 on 3S (pack
    type from the power-on battery check), x1.0 on 4S.
    - align: turn in place toward the tower; lost -> brake 0.3 s, then spin
    toward the side last seen.
    - charge: tower centered for 2 n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
2026-11-10 Match FSM 11/10: fork attack, center circle bypass, pushed-in escape, run log to Pi
    - Fork attack (brake -> insert -> burst) when the tower is close and centered (+-200 px)
    - Red center circle bypass when the tower is far; first-hit side escape table
    - Run log frames ESP -> Pi over UART, gyro heading pose (log only), Pi receiver service
    - Align damping, opening move turn times 290/565 ms, tilt guard 1 s
    - Battery check off still measures cells; bench GUI trim save fix
    - Schedule page: 11/10 progress and plan
2026-11-10 Pi backup and rebuild guide: settings, run logs, restore script
    - pi_backup/: tower colors and camera settings (were only on the Pi), 11/10 run logs,
    boot/network/service settings with Wi-Fi passwords removed, package lists
    - scripts/pi_restore.sh: one-shot setup on a fresh Raspberry Pi OS
    - scripts/pi_backup_pull.sh: stream a full Pi backup to the laptop
    - PI_RECOVERY.md: what to do first when the Pi dies
2026-11-11 Two-button rules, soft reset, combined bench, yellow calibration, old V1 robot
    Safety / buttons (11/11 decision):
    - Stopped: SW1 and SW2 both start; running: either held 0.5 s is an e-stop
    - E-stop is left with both buttons held together 0.5 s (soft reset, no re-init)
    - Buttons down at boot never start the robot; both pressed never start
    Firmware layout:
    - Match firmware now holds the bench and color calibration: power on with
    both buttons held 1 s -> bench, otherwise match (app/boot_mode)
    - Calibration: yellow added (front/rear pairs, 18 steps); yellow is then
    recognized and ignored
    Match FSM:
    - Opening turns back to 220/440 ms (new chip, trim reset)
    - Push-through: close opponent + f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
2026-11-13 Match day 11/13: reset report, 1 s watchdog with auto resume, escape and circle tuning, Pi ROI
    Firmware (V2 match):
    - Reset report: the drive state is copied into RTC RAM every loop; the next
    boot sends esp_reset_reason + that state to the Pi as a run-log Boot frame
    (kind 8), repeated every 2 s until the first start with a random boot id.
    - Task watchdog 1 s with panic (core dump), loop task subscribed; the
    emergency-stop wait loop feeds it. A watchdog reset while driving starts the
    run again without a button (no opening move). Not after an emergency stop,
    power-on, reset button, brownout or panic. AGENTS.md records the rule.
    - Escape: reverse/forward 450 -> 650, pushed-in 620 -> 7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
2026-11-13 Auto resume on any watchdog reset (not after an emergency stop)
    In the 11/13 match the robot rebooted and did not drive on: resume needed
    the RTC copy to say it was driving. Now a watchdog reset (5/6/7) starts the
    run at once also when it was waiting or the RTC copy was lost; only a reset
    while the emergency stop was latched (new RTC flag) blocks it. Power-on,
    reset button, brownout and panic still do not resume. AGENTS.md updated.
    Host tests (V2) pass. Flashed over COM4; not yet verified on the field.
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

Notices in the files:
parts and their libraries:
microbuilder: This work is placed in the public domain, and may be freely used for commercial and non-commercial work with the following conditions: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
